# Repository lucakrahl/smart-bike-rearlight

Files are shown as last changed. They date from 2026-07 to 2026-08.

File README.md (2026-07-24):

# Smart Bike Rear Light

Prototyp eines intelligenten IoT-Fahrrad-Rücklichts (Bachelorarbeit, Maschinenbau
& Produktentwicklung B.Eng.). ESP32-Firmware mit IMU-gesteuertem Schluss-/Brems-
licht, 433-MHz-Funk-Blinkern und BLE-Telemetrie an eine Web-App.

## Struktur (Monorepo)
| Ordner | Inhalt |
|---|---|
| `firmware/` | PlatformIO-Projekt (ESP32, Arduino-Framework) |
| `webapp/` | PWA / Web-Bluetooth-App (später) |
| `docs/` | **Project Bible** (SSOT) + Wissensdatenbank |
| `hardware/` | Schaltplan, BOM |
| `cad/` | Gehäuse (später) |
| `testdata/` | Sensordaten für Host-Logik-Tests |

## Quickstart
```bash
# Abhängigkeiten holen & Firmware bauen
cd firmware
pio run -e esp32dev

# Flashen & Serial-Monitor
pio run -e esp32dev -t upload
pio device monitor -b 115200

# Host-Unit-Tests der Logik (ohne ESP32)
pio test -e native
```

## Arbeiten mit Claude Code
`CLAUDE.md` im Repo-Root ist der Projektkontext (wird automatisch geladen).
**Zuerst `docs/project_bible.md` lesen** — das ist die Single Source of Truth.
Implementiert wird gegen die SRS (Bible Kap. 2); jede Umsetzung referenziert die
Anforderungs-ID(s). Reihenfolge der Module: `docs/roadmap.md`.

## Voraussetzungen
VS Code · PlatformIO IDE · Claude Code · Git. ESP32 NodeMCU DevKit C V2
(CP2102-Treiber). Board `esp32dev`, Partition `huge_app` (No-OTA), 115200 Baud.

## Wichtiger Hinweis
Das Notbrems-Blinken (FR-TL-07) ist **standardmäßig deaktiviert** — ein blinkendes
rotes Rücklicht ist nach § 67 Abs. 4 StVZO unzulässig (nur Experimental-/Messzweck).

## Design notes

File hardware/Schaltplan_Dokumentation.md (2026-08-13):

# Begleitdokumentation zum Schaltplan

**Elektrischer Schaltplan – Intelligentes IoT-Fahrrad-Rücklichtsystem**
**Bachelorarbeit · Hochschule Düsseldorf · Luca Krahl**
**Zeichnungsstand:** Rev. 1.3 vom 10.08.2026 · Blatt 1 von 1 · A4 Querformat
**Änderung gegenüber Rev. 1.2:** Die Gate-Pull-Down-Widerstände **R2, R4 und R6 (je 10 kΩ) sind entfallen** — sie sind nicht bestückt. Das Gate jedes MOSFET liegt ausschließlich über den Serienwiderstand R1/R3/R5 am GPIO, die Source direkt an der Masse-Sammelschiene. Neuer Befund B-9. Bauteilzahl 27 → 24.
**Änderung gegenüber Rev. 1.1:** (a) Die Drahtantenne ANT2 am SRX882S ist entfallen — sie ist nicht verbaut; der Pin ANT trägt jetzt eine Nichtanschluss-Markierung. (b) Vollständige Neuanordnung des Blattes: die Blockrahmen A und C überschnitten sich, und in Block D lagen die Versorgungssymbole auf dem Rahmen. (c) In Block D ersetzen zwei durchgehende Sammelschienen (+5 V und GND) die neun einzelnen Versorgungssymbole.
**Änderung gegenüber Rev. 1.0:** Position von SW1 korrigiert — der Schalter sitzt im Akkupfad zwischen U1 OUT+ und U2 VIN+.
**Quellen:** Project Bible Kap. 4/5 · `firmware/include/pins.h` und `config.h` (Commit `1178017`) · Datenblätter im Projekt · Verdrahtungsklärung vom 09.08.2026

---

## A. Komponentenübersicht

| Ref. | Bauteil | Funktion | Versorgung | Schnittstelle |
|---|---|---|---|---|
| BT1 | LiPo LP103454, 3,7 V, 2000 mAh | Energiespeicher | — | B+/B− an U1 |
| J1 | USB-C-Buchse (Bestandteil von U1) | Ladeanschluss, von außen zugänglich | 5 V extern | — |
| U1 | TP4056 Typ-C mit DW01 | Laderegler 1 A, Tiefentlade- und Kurzschlussschutz | USB-C 5 V | B+/B−, OUT+/OUT− |
| U2 | MT3608 | Aufwärtswandler 3,7 V → 5,00 V (Trimmer) | von U1 OUT+ | VIN/VOUT |
| SW1 | Rastender Drucktaster IP65, 8 mm | Ein/Aus **im Akkupfad zwischen U1 OUT+ und U2 VIN+** | — | — |
| C1 | Elektrolytkondensator 1000 µF | Pufferung Reglereingang | +5 V ↔ GND | — |
| C2 | Elektrolytkondensator 1000 µF | Pufferung Reglerausgang | +3V3 ↔ GND | — |
| U3 | ESP32-DevKitC-32E (WROOM-32E), AMS1117-3.3 onboard | Hauptrechner | VIN 5 V → 3V3 | GPIO, I²C, UART2, PWM, BLE |
| IC2 | GY-521 / MPU-6050 | IMU, Bremserkennung | +3V3 | I²C 0x68 |
| IC3 | BMP280 | Barometer, Höhe | +3V3 | I²C 0x76 |
| IC4 | Quectel L86-M33 | GNSS GPS+GLONASS, interne Patch-Antenne | +3V3 (VCC und V_BCKP) | UART, 9600 Bd |
| U4 | SRX882S V2.0 | 433-MHz-Empfänger, superheterodyn | +3V3 (VCC und CS) | Digitalausgang DATA |
| Q1–Q3 | IRLZ44N (3×) | Low-Side-PWM-Treiber | — | Gate an GPIO |
| R1/R3/R5 | 100 Ω (3×) | Gate-Serienwiderstand | — | — |
| RN1–RN3 | je 8 × 100 Ω parallel = 12,5 Ω | Strombegrenzung je LED-Kanal | in Reihe zur LED | — |
| D1 | LED rot, 3-W-COB | Schluss- und Bremslicht | Anode an +5 V | PWM über Q2 |
| D2 | LED gelb, 3-W-COB | Blinker links | Anode an +5 V | PWM über Q1 |
| D3 | LED gelb, 3-W-COB | Blinker rechts | Anode an +5 V | PWM über Q3 |
| — | QIACHIP-Handsender, 2 Tasten | Blinkerauslösung, Codes 10967538 / 10967537 | eigene Batterie | 433 MHz ASK, drahtlos |

**Nicht verbaut, aber bisher in der Stückliste geführt:** die GNSS-Antenne „Namvo". Der L86 nutzt seine interne Patch-Antenne (18,4 × 18,4 × 4 mm); der Pin EX_ANT ist unbeschaltet.

**Ebenfalls nicht verbaut:** eine Drahtantenne am SRX882S. Bis Rev. 1.1 war am Pin ANT eine λ/4-Drahtantenne von 17,3 cm eingezeichnet. Die Längenangabe war für 433,92 MHz rechnerisch korrekt (λ = c/f = 69,1 cm, λ/4 = 17,3 cm), entsprach aber nicht dem gebauten Aufbau: Es ist kein Draht angeschlossen. Der Pin ANT ist ab Rev. 1.2 als Nichtanschluss gezeichnet. Zur beobachteten Wirkung s. Befund B-7.

Der Micro-USB-Anschluss des DevKitC dient ausschließlich der Programmierung und ist im montierten Zustand nicht zugänglich. Seine Masse liegt hardwareseitig auf derselben GND-Schiene; beim Flashen wird der Akkupfad getrennt.

---

## B. Pinbelegung

| ESP32-Pin | Funktion | Angeschlossene Komponente | Netzname |
|---|---|---|---|
| GPIO21 | I²C SDA | IC2, IC3 | `I2C_SDA` |
| GPIO22 | I²C SCL | IC2, IC3 | `I2C_SCL` |
| GPIO16 | UART2 RX | IC4 TXD1 (Pin 2) | `GNSS_TXD1` |
| GPIO17 | UART2 TX | IC4 RXD1 (Pin 1) | `GNSS_RXD1` |
| GPIO4 | Digitaleingang RF | U4 DATA | `RF_DATA` |
| GPIO25 | PWM Blinker links | R1 → Q1 Gate | `PWM_BLINK_L` |
| GPIO26 | PWM Schluss-/Bremslicht | R3 → Q2 Gate | `PWM_BRAKE` |
| GPIO27 | PWM Blinker rechts | R5 → Q3 Gate | `PWM_BLINK_R` |
| VIN | Versorgung 5 V | +5-V-Schiene (U2 VOUT+) | `+5V` |
| 3V3 | Versorgungsausgang AMS1117 | IC2, IC3, IC4, U4, C2 | `+3V3` |
| GND | Bezugspotential | gemeinsame Masse | `GND` |

Der Interrupt-Pin des MPU-6050 bleibt unbeschaltet, weil GPIO4 durch den RF-Empfänger belegt ist; die IMU wird gepollt.

---

## C. Versorgungskonzept

Der Strompfad verläuft in einer Kette: Die USB-C-Buchse speist den TP4056, dieser lädt den LiPo-Akku über B+/B− mit maximal 1 A. Die Last hängt bewusst an **OUT+** und nicht an B+, damit der im Modul enthaltene DW01 seinen Tiefentlade- und Kurzschlussschutz auch für die Systemlast ausübt. Von OUT+ führt der Akkupfad über den rastenden Schalter **SW1** auf den Eingang des Aufwärtswandlers MT3608, dessen Trimmer auf 5,00 V eingestellt ist. Dessen Ausgang bildet die **+5-V-Schiene**, an der zwei Verbraucher hängen: der ESP32 über seinen VIN-Pin und die drei LED-Zweige über ihre Vorwiderstandsnetze. Der auf dem DevKitC verbaute AMS1117-3.3 erzeugt daraus die **+3,3-V-Schiene**, an der ausschließlich die vier Peripheriemodule liegen. Gepuffert wird an beiden Seiten des Reglers mit je 1000 µF (C1 am Eingang, C2 am Ausgang).

SW1 trennt den Eingang des Wandlers. Im ausgeschalteten Zustand ist damit die gesamte 5-V-Schiene einschließlich der LED-Zweige stromlos, und zusätzlich entfällt der Ruhestrom des MT3608. Der Ladepfad USB-C → U1 → BT1 bleibt davon unberührt; das Gerät lädt also auch ausgeschaltet.

### Strombilanz

| Betriebsfall | Entnahme an +5 V | Leistung | Strom aus BT1 (η = 0,90) |
|---|---|---|---|
| Schlusslicht (D1 bei 20 % Duty) + ESP32 + Sensorik | 159 mA | 0,80 W | 0,24 A |
| Bremslicht 100 % + ESP32 + Sensorik | 338 mA | 1,69 W | 0,51 A |
| Bremslicht + beide Blinker 100 % | 786 mA | 3,93 W | **1,18 A** |

Zugrunde gelegt: I_LED = (5 V − 2,2 V) / 12,5 Ω = 224 mA je Kanal; ESP32 mit Sensorik 113 mA an 5 V. Der Strom aus BT1 fließt vollständig über SW1, da der Schalter im Akkupfad sitzt. Rechnerische Laufzeit im Dauerbetrieb mit Schlusslicht: rund **8 h**. Die Werte sind berechnet, nicht gemessen.

---

## D. Kommunikationsschnittstellen

**I²C** verbindet den ESP32 über GPIO21 (SDA) und GPIO22 (SCL) mit IC2 (0x68) und IC3 (0x76) auf einem gemeinsamen Bus. Pull-Up-Widerstände existieren ausschließlich modulintern gegen +3,3 V; externe Widerstände sind nicht verbaut.

**UART2** verbindet den ESP32 mit dem GNSS-Modul: GPIO17 als Sendeleitung auf RXD1, GPIO16 als Empfangsleitung von TXD1, 9600 Bd, 8N1, 1 Hz Ausgaberate.

**GPIO** wird für den 433-MHz-Empfänger genutzt: U4 gibt die demodulierten Daten als Digitalsignal auf GPIO4 aus. Der Chip-Select-Pin von U4 liegt fest auf +3,3 V, der Empfänger ist damit dauerhaft aktiv.

**PWM** steuert alle drei Leuchtenkanäle über die LEDC-Peripherie mit 5 kHz und 8 bit Auflösung.

**BLE 4.2** überträgt die Telemetrie unidirektional vom Gerät zur iOS-App. Es ist eine reine Funkstrecke ohne Leitungsbezug und im Schaltplan als Annotation am ESP32 vermerkt.

**433 MHz** bildet die Strecke vom QIACHIP-Handsender zu U4. Der Sender ist ein gekauftes Gerät mit eigener Batterie und nicht Bestandteil der Leiterplatte.

---

## E. Elektrische Plausibilitätsprüfung

Die Prüfung wurde am fertigen Schaltplan durchgeführt. Die Verbindungsprüfung erfolgte maschinell über die aus der Zeichnung exportierte Netzliste; die Bewertungen darunter sind analytisch. **An der Schaltung wurde nichts geändert.**

### E.1 Verbindungsprüfung (maschinell, bestanden)

Die exportierte Netzliste enthält 32 Netze. Alle 24 Bauteile sind vollständig verdrahtet; jedes Netz trägt mindestens zwei Knoten. Die einzigen Einzelknoten sind die sechs bewusst offenen Pins des L86 (1PPS, FORCE_ON, AADET_N, RESET, EX_ANT, NC) sowie der Pin ANT des SRX882S — alle im Schaltplan mit Nichtanschluss-Markierungen versehen. Stichproben: `GND` verbindet 16 Knoten, `+3V3` acht, `+5V` sechs, `I2C_SDA` und `I2C_SCL` je drei. Die Schalterposition ist maschinell bestätigt: SW1 liegt zwischen `Net-(U1-OUT+)` und `Net-(U2-VIN+)`.

### E.2 Befunde

**B-1 · UART-Pegel überschreitet die spezifizierte Eingangsgrenze des L86 [relevant].**
Das Datenblatt des L86 (Tab. 3) gibt für die Digitaleingänge RXD1, RESET und FORCE_ON **VIHmax = 3,1 V** an. Der ESP32 treibt GPIO17 mit 3,3 V. Der Wert liegt damit **0,2 V über der spezifizierten Obergrenze**, aber deutlich unter dem absoluten Grenzwert von 3,6 V (Tab. 11) — eine Zerstörung ist nicht zu erwarten, der Betrieb erfolgt jedoch außerhalb der zugesicherten Bedingungen. In Gegenrichtung ist die Lage unkritisch: TXD1 liefert nominal 2,8 V gegen eine Eingangsschwelle des ESP32 von 0,75 · 3,3 V = 2,48 V, also 0,32 V Reserve. *Lösungsvorschlag:* Spannungsteiler 1 kΩ / 10 kΩ oder ein 1-kΩ-Serienwiderstand in der Leitung GPIO17 → RXD1. *Freigabe erforderlich, ich ändere nichts eigenmächtig.*

**B-2 · Verlustleistung des Boardreglers unter Spitzenlast [prüfen].**
Am AMS1117-3.3 des DevKitC hängen jetzt alle vier Peripheriemodule. Im ungünstigsten Fall summieren sich ESP32-Sendespitze (~250 mA), L86-Spitzenstrom (100 mA laut Datenblatt Tab. 12) und die beiden I²C-Sensoren (4 mA) auf rund 354 mA. Bei 1,7 V Spannungsabfall sind das **0,60 W** im SOT-223-Gehäuse; bei einem Wärmewiderstand von 60–100 K/W entspricht das 36–60 K Übertemperatur. Der Strom liegt innerhalb der Belastbarkeit des Reglers, die Verlustleistung ist aber nicht vernachlässigbar — und es ist derselbe Pfad, in dem der BLE-Brownout des Altboards saß. *Empfehlung:* im Rahmen der ohnehin offenen Messung NFR-PWR-02 mitmessen.

**B-3 · Laden unter Last [prüfen].**
Da die Last an OUT+ hängt, speist der TP4056 im Ladebetrieb gleichzeitig Akku und System. Der Laststrom fließt durch die Strommessung des Ladereglers; die Abschalterkennung kann dadurch verzögert oder verhindert werden. Das ist eine bekannte Eigenschaft dieser Topologie und kein Verdrahtungsfehler, gehört aber dokumentiert.

**B-4 · Fehlende hochfrequente Entkopplung [dokumentieren].**
Das L86-Datenblatt (Kap. 3.3) empfiehlt 10 µF und 100 nF unmittelbar am VCC-Pin. Verbaut sind ausschließlich die beiden 1000-µF-Elkos an den Schienen. Elektrolytkondensatoren haben oberhalb einiger 10 kHz keine wirksame Impedanz mehr; für die Störfestigkeit des GNSS-Empfängers ist das eine Abweichung von der Herstellerempfehlung.

**B-5 · Kein Verpolungs- und kein Überstromschutz [bestätigt, dokumentieren].**
Eine Sicherung existiert nicht. Ein Kurzschluss im LED-Zweig würde nur durch die Strombegrenzung des MT3608 und den DW01 des TP4056 begrenzt. Ein Verpolungsschutz an der Akkuklemme fehlt ebenfalls. Beides ist bewusster Aufbaustand und in Kap. 12 der Project Bible bereits als Risiko geführt.

**B-6 · Schalterstrom durch die Position im Akkupfad [prüfen].**
Da SW1 vor dem Aufwärtswandler sitzt, führt er dessen Eingangsstrom. Im Worst Case sind das **1,18 A** bei 3,7–4,2 V; auf der 5-V-Seite wären es bei gleicher Leistung nur 0,79 A gewesen. Für den verbauten 8-mm-Drucktaster liegt kein Datenblatt vor, Nennstrom und Kontaktwiderstand sind damit unbelegt. Ein erhöhter Kontaktwiderstand wirkt an dieser Stelle zusätzlich direkt auf den Eingangsspannungsbereich des MT3608, weil er den ohnehin niedrigen Akkuspannungspegel weiter absenkt. *Empfehlung:* Datenblatt beschaffen oder den Spannungsabfall über dem geschlossenen Kontakt unter Last messen — sinnvollerweise zusammen mit NFR-PWR-02.

### E.3 Als unkritisch geprüft

**GPIO-Belegung.** Die acht verwendeten Pins sind paarweise verschieden. GPIO4 ist kein Strapping-Pin. Die Strapping-Pins GPIO0, 2, 5, 12 und 15 sind unbeschaltet. GPIO16 und GPIO17 sind beim WROOM-32E frei nutzbar — die Einschränkung gilt nur für WROVER-Module mit PSRAM. GPIO25 bis 27 sind als Digitalausgänge ohne Boot-Bedingungen verwendbar.

**I²C-Bus.** Adressen 0x68 und 0x76 kollidieren nicht. Zwei modulinterne Pull-Ups von typisch je 4,7 kΩ ergeben parallel etwa 2,35 kΩ; daraus folgt ein Low-Strom von 1,4 mA, deutlich unter der Senkfähigkeit des ESP32 von 3 mA nach I²C-Spezifikation. Die Anstiegszeit beträgt bei geschätzten 50 pF Busskapazität rund 0,1 µs gegen ein zulässiges Maximum von 1 µs im Standard-Modus. Beide Sensoren liegen an derselben 3,3-V-Schiene wie der Controller, ein Pegelwandler ist nicht erforderlich.

**UART-Kreuzung.** TX und RX sind korrekt gekreuzt (GPIO17 → RXD1, TXD1 → GPIO16).

**MOSFET-Ansteuerung.** Der IRLZ44N ist ein Logic-Level-Typ mit einer Gate-Schwellspannung von 1,0 bis 2,0 V. Bei 3,3 V Ansteuerung und 224 mA Laststrom liegt der Durchlasswiderstand bei etwa 0,05 Ω, die Verlustleistung damit bei 2,5 mW je Transistor — thermisch belanglos. Die Gate-Zeitkonstante beträgt mit 100 Ω und einer Eingangskapazität von rund 3,3 nF etwa 0,33 µs; bei 5 kHz Schaltfrequenz (200 µs Periode) entfallen damit unter 1 % der Periode auf die Umschaltvorgänge. Ein Gate-Pull-Down ist **nicht bestückt**; zur Folge für den Reset- und Bootzustand s. Befund B-9. Der Transistor ist mit 47 A Nennstrom für 224 mA erheblich überdimensioniert; das ist kein Fehler, sondern eine Folge der Bauteilverfügbarkeit und darf so begründet werden.

**LED-Zweige.** Jeder Kanal besitzt eine Strombegrenzung. Die Verlustleistung im Widerstandsnetz beträgt 0,63 W, verteilt auf acht Widerstände also 78 mW je Bauteil — bei 0,25-W-Typen eine Auslastung von 31 %.

**Thermische Stabilität der Vorwiderstandslösung.** Der in Kap. 12 der Project Bible geführte Verdacht auf thermisches Weglaufen lässt sich entkräften. Mit I = (5 V − V_f)/12,5 Ω und einem Temperaturkoeffizienten der Flussspannung von etwa −2 mV/K ergibt sich dI/dT = 0,16 mA/K. Über eine Erwärmung von 50 K steigt der Strom damit um 8 mA, also um 3,6 %. Entscheidend ist, dass über dem Widerstand mit 2,8 V mehr Spannung abfällt als über der LED mit 2,2 V — die Schaltung ist dadurch hinreichend steif. Ein thermisches Weglaufen ist bei dieser Dimensionierung **nicht zu erwarten**. Das Risiko kann in der Bible entsprechend herabgestuft werden.

---

**B-7 · SRX882S ohne Antenne betrieben [beobachtet, nicht gemessen].**
Der Empfänger arbeitet ohne angeschlossene Antenne; der Empfang erfolgt über die Anschlussfahne und die Leiterbahnen des Moduls. Der Verfasser berichtet, dass die Funkverbindung ohne den zuvor angeschlossenen 17,3-cm-Draht **zuverlässiger** arbeitet als mit ihm.

Das ist plausibel, aber nicht gemessen. Eine λ/4-Monopolantenne setzt eine leitende Gegenfläche (Counterpoise) von mindestens λ/4 Ausdehnung voraus; auf einem Lochrasteraufbau ohne durchgehende Massefläche fehlt diese. Der Draht wirkt dann weniger als abgestimmter Strahler denn als breitbandige Sammelfläche und koppelt bevorzugt die Störspektren des MT3608-Schaltreglers und der 5-kHz-PWM-Stufe ein, die beide unmittelbar daneben liegen. Der Superheterodyn-Empfänger verliert dadurch Rauschabstand, obwohl seine Empfindlichkeit steigt. Ohne Draht sinken Empfindlichkeit **und** Störpegel; bei den hier auftretenden Entfernungen von wenigen Metern überwiegt offenbar der Gewinn an Rauschabstand.

**Einordnung.** Die Aussage, ohne Antenne sei der Empfang besser, ist eine Beobachtung des Verfassers und keine Messung. Belastbar wäre sie erst über eine Reichweitenmessung mit und ohne Draht bei gleicher Sendeleistung und gleicher Ausrichtung. Diese Messung ist nach dem Umfangsschnitt vom 10.08.2026 nicht Teil der Arbeit. Für die Zeichnung gilt der gebaute Zustand: kein Draht, Nichtanschluss am Pin ANT. In den Ausblick gehört der Hinweis, dass eine durchgehende Massefläche unter dem Empfängermodul die Voraussetzung dafür wäre, eine abgestimmte Antenne überhaupt sinnvoll zu betreiben.

**B-9 · Kein Gate-Pull-Down bestückt [dokumentierte Abweichung].**
Die ursprünglich vorgesehenen Widerstände R2, R4 und R6 (je 10 kΩ, Gate gegen Masse) sind im Aufbau nicht vorhanden. Das Gate jedes IRLZ44N ist ausschließlich über den Serienwiderstand von 100 Ω mit dem zugehörigen GPIO verbunden, die Source liegt direkt an Masse.

**Wirkung im Normalbetrieb: keine.** Sobald die Firmware den Pin über `ledcAttach()` als PWM-Ausgang konfiguriert hat, treibt der GPIO das Gate niederohmig; der Pull-Down wäre in diesem Zustand ohnehin nur eine parallele Last von 10 kΩ und ohne Einfluss. Die Gate-Zeitkonstante von 0,33 µs bleibt unverändert.

**Wirkung außerhalb des Normalbetriebs.** Zwischen dem Aufheben des Reset und der Pin-Konfiguration in `setup()` ist der GPIO hochohmig. Ohne Pull-Down ist das Gate in diesem Fenster **potentialfrei**. Bei einer Eingangskapazität von rund 3,3 nF und einer Gate-Schwellspannung des IRLZ44N von 1,0 bis 2,0 V genügt eine geringe eingekoppelte Ladung, um den Transistor teilweise leitend werden zu lassen. Die Dauer des Fensters umfasst Bootloader und Arduino-Initialisierung und liegt in der Größenordnung einiger hundert Millisekunden; sie wurde **nicht gemessen**.

**Bewertung der Folgen.** Für den roten Kanal ist die mögliche Fehlwirkung ein kurzzeitiges Aufleuchten des Schluss-/Bremslichts — für eine Rückleuchte die sichere Richtung, weil sie die Sichtbarkeit erhöht statt sie zu verringern. Für die beiden gelben Kanäle wäre es ein kurzzeitiges Fehlsignal in eine Abbiegerichtung; da es ausschließlich unmittelbar nach dem Einschalten auftreten kann, also im Stand, ist die praktische Gefährdung gering. Beim Flashen und bei den Boot-Kontrollen ist ein solches Aufleuchten **nicht beobachtet** worden.

**Warum keine Nachbesserung erfolgt.** Ein interner Pull-Down des ESP32 (typisch 45 kΩ) ließe sich in `setup()` aktivieren, wäre aber erst nach der Pin-Konfiguration wirksam und würde das Fenster deshalb nur verkürzen, nicht schließen. Vollständig schließen lässt es sich nur durch einen physischen Widerstand am Gate. Die Firmware ist seit dem 10.08.2026 eingefroren (Project Bible Kap. 12.2), und der Aufbau wird nicht mehr geändert. Der Punkt wird deshalb als **dokumentierte Abweichung** geführt und gehört als konkrete Empfehlung in den Ausblick: In einer Leiterplattenausführung ist ein Gate-Pull-Down von 10 bis 100 kΩ je Kanal vorzusehen.

## F. Offene Punkte

| Nr. | Punkt | Status |
|---|---|---|
| F-1 | Pegelanpassung GPIO17 → L86 RXD1 (Befund B-1) | Entscheidung des Verfassers erforderlich |
| F-2 | Messung der Verlustleistung am AMS1117 unter Spitzenlast (B-2) | offen, mit NFR-PWR-02 zu verbinden |
| F-3 | Verhalten des TP4056 beim Laden unter Last (B-3) | offen, messtechnisch zu prüfen |
| F-4 | Fehlende 10 µF / 100 nF am L86-VCC (B-4) | dokumentierte Abweichung |
| F-5 | Datenblatt der 3-W-COB-LED (Hersteller Vrabocry) | fehlt weiterhin; V_f = 2,2 V ist Mittelwert der Produktangabe 2,0–2,4 V |
| F-6 | Photometrischer Nachweis der Lichtstärke nach § 67 StVZO | offen, separate Messung |
| F-7 | Wirkungsgrad des MT3608 unter realer Last | angenommen η = 0,90, nicht gemessen |
| F-8 | Namvo-GNSS-Antenne in der Stückliste als nicht verbaut kennzeichnen | Dokumentationskorrektur |
| F-9 | Anordnung der Patch-Antenne im Gehäuse | Datenblatt fordert freie Sicht nach oben, nichtmetallisches Gehäuse, ≥ 10 mm Abstand zur BLE-Antenne des ESP32 |
| F-10 | Nennstrom und Kontaktwiderstand von SW1 (B-6) | Datenblatt fehlt; Messung des Spannungsabfalls unter Last empfohlen |
| F-11 | Reichweite der 433-MHz-Strecke ohne Antenne (B-7) | Beobachtung des Verfassers, nicht gemessen; Vergleichsmessung mit und ohne Draht wäre der Beleg |
| F-12 | Stückliste: Drahtantenne 17,3 cm am SRX882S als nicht verbaut kennzeichnen | Dokumentationskorrektur analog F-8 |
| F-13 | Stückliste: Positionen 10-kΩ-Pull-Down (3×) **streichen** statt ergänzen (B-9) | Sie sind nicht bestückt; der bisherige offene Punkt forderte fälschlich ihre Aufnahme |
| F-14 | Dauer des potentialfreien Gate-Fensters nach Reset messen (B-9) | Nicht gemessen; für die Bewertung der Fehlwirkung wäre der Wert die fehlende Größe |

Alle Größen im Schaltplan stammen aus belegten Projektquellen. Erfunden wurde nichts; die einzige rechnerische Annahme ist die mittlere Flussspannung von 2,2 V, die als solche gekennzeichnet ist.

---

## G. Dateien

| Datei | Inhalt |
|---|---|
| `schaltplan_fahrrad_ruecklichtsystem.kicad_sch` | KiCad-7-Schaltplan, in KiCad direkt zu öffnen und zu bearbeiten; die Symbolbibliothek ist in der Datei eingebettet, es werden keine externen Bibliotheken benötigt |
| `schaltplan_fahrrad_ruecklichtsystem.pdf` | Vektor-PDF, A4 Querformat, schwarzweiß — für die Bachelorarbeit |
| `schaltplan_fahrrad_ruecklichtsystem_farbe.pdf` | dieselbe Zeichnung im KiCad-Farbschema |
| `schaltplan_fahrrad_ruecklichtsystem.svg` | Vektorgrafik zur Weiterverarbeitung |
| `netzliste.net` | aus der Zeichnung exportierte Netzliste (Grundlage der Verbindungsprüfung E.1) |
| `Schaltplan_Dokumentation.md` | dieses Dokument |
| `gen.py`, `symlib.py` | Erzeugungsskripte, mit denen die Zeichnung reproduzierbar ist |

Die Zeichnung enthält keine Informationen, die ausschließlich über Farbe transportiert werden; die schwarzweiße Fassung ist vollständig gleichwertig.

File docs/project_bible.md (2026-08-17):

# Project Bible — Smartes Fahrrad-Rücklicht
**Bachelorarbeit Krahl · Maschinenbau & Produktentwicklung (B.Eng.)**
**Version 0.25 · Stand 17.08.2026 · Status: aktiv gepflegt (Single Source of Truth)**

> Diese Project Bible ist die oberste Wissensinstanz des Projekts. Bei Widersprüchen zwischen Chat-Historie und Project Bible gilt ausschließlich die Project Bible. Chats dienen der Diskussion und Entscheidungsfindung; der offizielle Projektstand steht ausschließlich hier.

---

## 0. Meta & Änderungsprotokoll

### 0.1 Geltungsregeln
- Die Project Bible bildet jederzeit den offiziellen Entwicklungsstand des Gesamtsystems ab.
- Widerspricht eine frühere Chat-Aussage der Project Bible, gilt die Project Bible.
- Kapitel 10 (Entwicklungsentscheidungen) wird als lebendes Änderungsprotokoll geführt.
- Trennung der Ebenen: **Project Bible** = offizieller Stand · **Kapitel 10** = Begründung der Entscheidungen · **Chats** = Diskussion.

### 0.2 Kennzeichnungslegende
- **[gesichert]** — durch mehrere Quellen bestätigt oder vom Nutzer freigegeben.
- **[Annahme]** — plausibel, aber messtechnisch/dokumentarisch noch nicht verifiziert.
- **[offen]** — in Klärung, noch nicht entschieden.
- **[geplant]** — beschlossen und spezifiziert, aber noch nicht umgesetzt oder noch nicht verifiziert.

### 0.3 Änderungsprotokoll
| Version | Datum | Änderung | Anlass |
|---|---|---|---|
| 0.1 | 21.07.2026 | Erstkonsolidierung als Analysedokument. | Projektaufnahme |
| 0.2 | 21.07.2026 | 12-Kapitel-Zielstruktur. SRS-Block A. | Freigabe Block A |
| 0.3 | 21.07.2026 | SRS-Block B (Zustandsmodell). | Freigabe Block B |
| 0.4 | 21.07.2026 | SRS-Block C (Detaillogik); Norm-Grundlage § 67/ECE. | Freigabe Block C |
| 0.5 | 21.07.2026 | SRS-Block D + E (Fehler & Sicherheit). | Freigabe Block D+E |
| 0.6 | 21.07.2026 | SRS-Block F (nichtfunktional); Akku LP103454. | Freigabe Block F |
| 0.7 | 21.07.2026 | SRS-Block G + H. **SRS (Phase 1) vollständig.** | Freigabe Block G+H |
| 0.8 | 21.07.2026 | Phase 3: Monorepo + PlatformIO angelegt, Umgebung lauffähig (pioarduino, Core 3.3.11). | Setup abgeschlossen |
| 0.9 | 21.07.2026 | M1 (Rücklicht-Region R2) in Umsetzung: FSM + Host-Tests. Detailklarstellungen FR-TL-03, FR-TL-06, FR-TL-07. | Implementierung M1 |
| 0.10 | 26.07.2026 | Implementierungsstand M1–M4 hardwarevalidiert, M5 Teil A (BMP280) validiert; zentrale I²C-Bus-Initialisierung; BMP280 FORCED-Mode. | Impl. M1–M5A |
| 0.11 | 29.07.2026 | App-Plattform: native iOS-App (Core Bluetooth) statt Web-App/PWA. | Plattform-Entscheidung App |
| 0.12 | 30.07.2026 | BLE-Brownout-Fallstudie; Board-Wechsel auf Espressif ESP32-DevKitC-32E beschlossen. | Root-Cause-Analyse BLE-Brownout |
| 0.13 | 01.08.2026 | Board-Tausch ausgeführt und validiert; iOS-App-Stand nachgezogen. | BLE-Validierung + App-Stand |
| 0.14 | 05.08.2026 | Telemetrie-Frame um `brake_light_pct` erweitert, 80→81 Byte, Schema-Version 1→2. | Frame-Erweiterung |
| 0.15 | 05.08.2026 | Serial-Bench-Validierung der Bremslicht-Logik; iOS-App am realen iPhone verifiziert. | Bench-Validierung |
| 0.16 | 06.08.2026 | **Feldtest 06.08.2026:** IMU-Bremserkennung im Realbetrieb falsifiziert (r = −0,132, n = 939). Ursache analytisch belegt. Neues Kap. 9.4. Architekturentscheidung V-B. | Feldtest-Auswertung |
| **0.17** | **09.08.2026** | **Große Revision. (a) Stufe 1 (`motion_filter`, Normbetrags-Gate) implementiert, host-getestet und am 08.08.2026 im Feld verifiziert — die Bremserkennung funktioniert; neues Kap. 9.5. Der Validierungsstatus von `motion_filter` wird von „im Feld falsifiziert" auf „im Feld verifiziert" heraufgestuft. (b) Zwei neue Firmware-Befunde: die Mindesthaltezeit nach FR-TL-06 ist im Fahrbetrieb unwirksam (Mangel), und `brake_decel_ms2` trägt eine geschwindigkeitsabhängige Grundlinie (quantifizierte Grenze). (c) Zeitverhalten erstmals im Fahrbetrieb gemessen: 6,7 ms Worst Case statt 0,651 ms am Prüfstand. (d) Methodische Korrektur: die Zahl r = −0,132 aus v0.16 wurde ohne Berücksichtigung der Latenz der GNSS-Referenzkette gerechnet und ist als Gütemaß nicht belastbar. (e) Elektronik vollständig geklärt und dokumentiert: Schaltplan Rev. 1.0 erstellt (Kap. 5.4), sechs offene Verdrahtungspunkte geschlossen, Energiebilanz methodisch korrigiert (13 h → ~8 h), GNSS-Antenne als nicht verbaut erkannt. (f) Einbaulage der IMU um 180° gedreht; Achsentransformation spezifiziert, noch nicht implementiert.** | Messfahrt, Schaltplan, Verdrahtungsklärung |
| **0.18** | **09.08.2026** | **Korrektur der Schalterposition.** SW1 sitzt im **Akkupfad zwischen U1 OUT+ und U2 VIN+** und trennt damit den Eingang des Aufwärtswandlers — nicht, wie in v0.17 und im Schaltplan zunächst dargestellt, zwischen MT3608-Ausgang und 5-V-Schiene. Funktional bleibt die Wirkung gleich (die gesamte 5-V-Schiene ist stromlos), elektrisch ändert sich der Schalterstrom: er fließt nun auf der Akkuseite und beträgt im Worst Case 1,18 A statt 0,79 A. Neuer Befund B-6. Schaltplan Rev. 1.1, Kap. 4.1, 5.1, 5.2, 5.4, 11.2 und 12 angepasst. | Korrekturhinweis des Verfassers |
| **0.19** | **10.08.2026** | **Firmware-Abschluss (Commit `835c7b3`, geflasht).** (a) Einbaulage-Transformation implementiert und auf das Gerät gebracht: `imu_mount_orientation.h` an der Treibergrenze, `IMU_MOUNT_SIGN_X/Y/Z` = −1/−1/+1 auf Beschleunigung und Drehrate, eigener Host-Test. Kap. 4.3 wechselt von [geplant] auf [umgesetzt]. (b) **Mangel M-01 behoben:** der Haltewert der Mindesthaltezeit wird nur noch oberhalb der Einschaltschwelle nachgeführt; Regressionstest ergänzt, der das Hystereseband monoton durchläuft. (c) **Umfangsschnitt Firmware:** FR-CFG-02 (serielles Kalibrier-Interface) und FR-CFG-03 (NVS-Konfiguration) werden nicht umgesetzt und als begründete Abgrenzung geführt (neues Kap. 12.2); alle Kalibrierwerte sind Übersetzungszeit-Konstanten. (d) Auslieferungsstand: alle Debug-Ausgaben entfernt, `DEBUG_SERIAL = false`. Daraus folgt eine **Korrektur an Befund B7**: die Zuordnung der 6,7 ms Worst-Case-Schleifenzeit allein zum GNSS-Slot war nicht belegt, weil drei 1-Hz-Debug-Prints im selben Messfenster lagen (Kap. 9.5.5). (e) `lib_deps` versionsfest gepinnt (Reproduzierbarkeit, NFR-EXT-01); tote Symbole entfernt; alle `TODO(offen)`-Marker in begründete Abgrenzungen umformuliert. (f) Host-Tests **126/126** grün. **Die Firmware ist damit abgeschlossen und eingefroren.** | Firmware-Abschluss |
| **0.20** | **10.08.2026** | **Werkstoffkorrektur Gehäuse: PETG statt PLA.** Frühere Fassungen nannten in Kap. 4.1 und Kap. 8 durchgängig PLA; gefertigt wird im FDM-Verfahren aus PETG. Die Angabe war eine Fehlangabe, keine Änderung der Auslegung. Thermisch günstiger (höhere Glasübergangstemperatur, zäher, witterungsbeständiger). Ergänzt: Verbindungstechnik mit Einschmelzgewinden M3 × 5 × 5 sowie Schrauben M3 × 6 und M3 × 8; Hinweis, dass die Konstruktion bearbeitet und gedruckt ist und der Konstruktionsstand noch aufzunehmen ist. | Korrekturhinweis des Verfassers |
| **0.21** | **11.08.2026** | **Normkorrektur, konstruktive Anforderungen und Quellenprüfung.** (a) **ECE R6 ist für Fahrrad-Fahrtrichtungsanzeiger nicht einschlägig.** § 67 Abs. 5 StVZO nennt UN/ECE R50 bzw. UN R148 (Genehmigung), R74 (Anbau) und R60 (Bedienteile). Der Zahlenwert 1,5 Hz ist primär in UN-R53 § 6.3.8.1 belegt (90 ± 30/min) und wird als **Analogie** geführt, weil R53 für Krafträder gilt. Kap. 0.4, 2.7, 2.8 und das Glossar angepasst. (b) **§ 67 Abs. 5 StVZO lässt Fahrtrichtungsanzeiger am Fahrrad ausdrücklich zu** — die gegenteilige Aussage in `Parameterherleitung.md` ist zu korrigieren. (c) **Neuer Block 2.13: zehn konstruktive Anforderungen (KON-01 bis KON-10)**, abgeleitet aus dem eingefrorenen Elektronikstand, mit Unterscheidung in Forderung und Wunsch. (d) **Trockenbetrieb als ausdrückliche Systemgrenze**: es gibt keine Umgebungsanforderungen, ein Dichtheitsnachweis wurde nicht geführt. (e) Vier Befunde aus der Datenblattprüfung des IRLZ44N und aus [Hering u. a.]: C_iss ist 1700 pF und nicht 3,3 nF, R_DS(on) ist bei 3,3 V nicht spezifiziert, V_GS(th) ist bei 250 µA definiert und keine Vollansteuerungsgrenze, und der Temperaturkoeffizient der LED-Durchlassspannung beträgt **−1 mV/K** statt −2 mV/K. Kap. 5.4 und 12.1 angepasst. (f) Rollen der Funkstrecke geklärt und Kennwerte des SRX882S aufgenommen; die Empfindlichkeit beträgt −107 dBm und nicht −114 dBm. (g) Werkstoffbegründung PETG auf die thermische Belastung gestützt, Witterungsbeständigkeit als Nebeneffekt geführt. | Quellenprüfung, Kapitel 3 der Thesis |
| **0.22** | **12.08.2026** | **Rücknahme des GNSS-Integritätsbefunds und Kapitel 4 der Thesis.** (a) **Der Befund „73 km/h Scheingeschwindigkeit im Stand bei FIX_OK" ist zurückgezogen.** Fahrt 5 des Feldtests vom 06.08.2026 wurde nach Klarstellung des Verfassers aus dem *fahrenden* Auto durchgeführt. Die gemeldete Geschwindigkeit war damit real und kein Integritätsfehler. Die Abdeckung hat das Signal nicht ausreichend gedämpft, der Versuch ist ergebnislos und **kein Beleg**. Kap. 0.4, 9. (Validierungstabelle), 9.4, 10 und 12.1 angepasst. (b) Die Architekturentscheidung V-B bleibt unverändert bestehen. Sie trägt auf vier voneinander unabhängigen, weiterhin belegten Punkten: Höchstrate 10 Hz gegen 100 Hz, Latenz 200–400 ms gegen NFR-RT-01, rund 20 s bis zum Erstfix und ein 90-%-Quantil des Differentiationsrauschens bis 1,97 m/s² gegen eine Ansprechschwelle von 2,0 m/s². (c) **Kapitel 4 der Thesis (Systemkonzept) geschrieben**, mit Tabelle 4-1 (Variantenvergleich) und den Abbildungen 4-1 bis 4-4. Das Kriterium „wissenschaftlicher Gehalt für die Arbeit" aus der internen Variantenbewertung wird in der Thesis-Tabelle bewusst nicht geführt, weil es kein ingenieurtechnisches Kriterium ist. (d) Der ausgelieferte Firmwarestand entspricht funktional V-C mit vorbereiteter, aber abgeschalteter Stufe 2. Diese Formulierung wird in der Arbeit so verwendet. | Klarstellung des Verfassers, Thesis-Kapitel 4 |
| **0.23** | **13.08.2026** | **Hardwarestand gegen Fotos, Schaltplan Rev. 1.3 und zwei neue Datenblätter abgeglichen; Kapitel 5 der Thesis geschrieben.** (a) **Bestückungskorrekturen:** SW1 ist ein **Wippschalter** und kein Drucktaster IP65. Die **Gate-Ableitwiderstände R2/R4/R6 sind nicht bestückt** — Schaltplan Rev. 1.3 führt das als Befund B-9. **ANT2 ist nicht verbaut**, der Empfang erfolgt über die Anschlussflächen des Moduls; der Widerspruch zwischen Kap. 4.1 und 11.2 ist damit aufgelöst. (b) **Datenblatt der roten Leuchte beschafft** (NTE30180-R, typgleiches Vergleichsbauteil): Dauerstrom **800 mA** statt der bisher geführten 400–500 mA, Durchlassspannung 2,0–2,6 V bei 400 mA, Sperrschichttemperatur typisch 115 °C gegen Grenzwert 120 °C. Der Kanalstrom wird als Spanne **208 bis 240 mA** mit 224 mA als Rechenwert geführt. (c) **Wirkungsgrad des MT3608 bleibt eine Annahme.** Das Datenblatt nennt nur „bis zu 97 %" ohne Arbeitspunkt und ohne Kennlinie; η = 0,90 wird beibehalten, die Laufzeit zusätzlich als Spanne 7,9 bis 8,8 h angegeben. (d) **Latenzangabe korrigiert:** die 200–400 ms waren eine eigene Abschätzung und nicht aus dem Datenblatt belegbar. Maßgeblich ist der gemessene Versatz von 1,6 bis 2,0 s aus der Messfahrt. Ratengrenze des Empfängers und Grenze der seriellen Schnittstelle werden getrennt geführt. (e) **Funkstrecke erstmals gemessen:** 19 von 20 bzw. 18 von 20 erkannten Tastendrücken in Einbaulage mit Körper im Signalweg, ohne Drahtantenne. Der offene Punkt aus Kap. 11.2 ist damit geschlossen. (f) Schaltplanstand auf **Rev. 1.3 (10.08.2026)** gehoben. (g) Fotodokumentation des Aufbaus in die Datengrundlage aufgenommen. | Fotoabgleich, Datenblätter, Thesis-Kapitel 5 |
| **0.24** | **13.08.2026** | **Präzisierungen aus der Quellenarbeit zu Kapitel 5.1.** (a) Das **ersetzte Mikrocontrollerboard wird namentlich geführt**: AZ-Delivery ESP-32 Dev Kit C V2, belegt über die Herstelleranleitung AZ281 aus der Projektablage. Bisher stand dort nur „Board eines anderen Anbieters". (b) **Wichtige Präzisierung zum Board-Tausch:** Beide Boards tragen denselben Reglertyp AMS1117-3.3. Der Brownout ist deshalb **keine generische Eigenschaft** dieses Reglertyps oder der Plattform, sondern nach der Fallstudie eine Grenze oder ein Defekt des konkreten Altboards, wahrscheinlich durch umfangreiches Rework verursacht. Diese Einordnung ist im Thesis-Text zu übernehmen. (c) **L86 präzisiert:** Empfang von GPS und GLONASS auf L1; SBAS und QZSS sind unterstützt, am Einsatzort ist davon nur SBAS in Form von EGNOS wirksam, weil QZSS ein regionales System über Asien und Ozeanien ist. (d) Belegliste auf [17] bis [27] erweitert; die Alternativen der Komponentenauswahl sind jetzt einzeln belegt. | Quellenarbeit Kapitel 5.1 |
| **0.25** | **17.08.2026** | **Thesis-Kapitel 6 bis 10 abgeschlossen, Anhangsstruktur festgeschrieben, Projektarchiv veröffentlicht.** (a) **Anhangsstruktur der Thesis verbindlich festgelegt** (neues Kap. 12.3): A Schaltplan, Stückliste und Bestückungsplan · B Anforderungsliste mit Nachweisführung · C Projektarchiv, Rohdaten und Auswertungsskripte · D Herleitung der Zahlenwerte der Signalaufbereitung · E Schnittstellenbeschreibung des Telemetriepakets · F Dokumentation der Nutzung generativer KI-Werkzeuge. Die KI-Dokumentation steht ausdrücklich an letzter Stelle. (b) **Nachweisart je Anforderung festgelegt** — der seit Kap. 2.13 offene Punkt ist geschlossen. Vier Arten: Analyse, Inspektion, Test, Messung. Zusätzlich eine vierstufige Bewertungsskala. 73 der 79 Anforderungen sind erfüllt und nachgewiesen; eingeschränkt sind FR-TL-06, FR-TL-07, FR-CFG-02, FR-CFG-03, NFR-PWR-02 und KON-06. (c) **Lücke im Anforderungsbestand erkannt:** Für die Funkstrecke existiert keine Anforderung an die Erkennungsrate, obwohl sie die einzige Eingabeschnittstelle des Systems ist. (d) **Neuer Messbefund zum Zeitverhalten:** Die erhöhten Schleifenzeiten treten periodisch mit 1,00 s auf, insgesamt 175 Ereignisse über 177,86 s. (e) **Randbedingung von Prüfstandsversuch D festgeschrieben:** Dauerbremsung von 3,9 m/s² über vier Sekunden, alte und neue Aufbereitung parallel auf derselben Eingangsfolge. (f) **Formelzeichen vereinheitlicht:** Der Neigungswinkel der Fahrbahn trägt das Zeichen β, α bleibt dem Gewichtungsfaktor des Filters vorbehalten, δ wird neu geführt. (g) **Tabelle 6-1 aus dem Fließtext in Anhang D verlagert.** Der Wert 6,0 m/s² für das Rückfallkriterium war bisher nur im Quelltext geführt und wird in den Thesis-Text aufgenommen. (h) **Korrelationswerte in der Thesis wieder aufgenommen:** +0,85 und im Median +0,15 bei einheitlich herausgerechnetem Versatz von 2,0 s. (i) **Projektarchiv veröffentlicht** unter https://github.com/lucakrahl/smart-bike-rearlight, eingefrorener Stand a6e3a0c vom 17.08.2026. Als Folge: die beiden Transferdokumente zur Firmware werden entfernt, der Feldtestbericht erhält einen datierten Nachtrag mit drei zurückgezogenen Befunden, cad/README.md wird von PLA auf PETG korrigiert. | Thesis-Kapitel 6–10, Gesamtdurchsicht, Veröffentlichung des Archivs |

### 0.4 Datengrundlage
| Quelle | Zeitstempel | Aussagekraft |
|---|---|---|
| Projektübergabe-Dokument | „Stand Juni 2026" | Detaillierteste Einzelquelle der Frühphase |
| **Repo `smart-bike-rearlight`, Commit `835c7b3` (Firmware-Abschluss)** | **10.08.2026** | **Maßgeblicher und endgültiger Firmware-Stand** |
| Repo `smart-bike-rearlight`, Commit `1178017` | 07.08.2026 | Stand der Messfahrt-Aufzeichnung vom 08.08.2026 |
| `firmware/include/pins.h`, `config.h` | Commit `835c7b3` | Verbindliche Pin- und Parameterquelle |
| **Verdrahtungsklärung mit dem Verfasser** | **09.08.2026** | **Sechs bis dahin offene Elektronikpunkte geklärt (Kap. 5)** |
| **Schaltplan Rev. 1.0 (`schaltplan_fahrrad_ruecklichtsystem.kicad_sch/.pdf`)** | **09.08.2026** | **Gültiger Zeichnungsstand; ersetzt Schaltplan v2** |
| ~~Schaltplan v2.pdf~~ | 20.05.2026 | **überholt** — an drei Stellen nachweislich falsch, nicht mehr verwenden |
| **Messfahrt-Export `SmartBikeRearLightFahrt202608082245.csv`** | **08.08.2026** | **Feldnachweis Stufe 1, Schema v3, 10 Hz** |
| Feldtest-Exporte 06.08.2026 (sechs CSV, Schema v2, 1 Hz) | 06.08.2026 | Vorher-Vergleich. **Fahrt 5 wurde aus dem fahrenden Auto durchgeführt und ist kein Integritätsnachweis** (Klarstellung des Verfassers 12.08.2026) |
| `Uebersicht.xlsx` (BOM) | 17.02.2026 | Stückliste mit Preisen — korrekturbedürftig (Kap. 11) |
| Datenblätter (ESP32-WROOM-32E, BMP280, GY-521, IRLZ44N, MT3608, TP4056, **Quectel L86 Hardware Design V1.0**, **NTE30180 Rev. 9-21**) | Herstellerstand | Referenzwerte. NTE30180 ist ein **typgleiches Vergleichsbauteil** zur roten Leuchte, die Typidentität mit dem verbauten Teil ist nicht belegt |
| **Angebotsangabe des Händlers zur gelben Leuchte** | abgerufen 12.08.2026 | 590–595 nm, 2,2–2,4 V. **Kein Datenblatt**, die Stromangabe widerspricht sich im Angebot selbst |
| **Schaltplan Rev. 1.3** (`schaltplan_fahrrad_ruecklichtsystem.kicad_sch/.pdf`) | **10.08.2026** | **Gültiger Zeichnungsstand; ersetzt Rev. 1.1** |
| **Fotodokumentation des Aufbaus** (Steckaufbau, handschriftlicher Bestückungsplan, Lochrasterplatine, Einbau im Gehäuse) | 08/2026 | Belegmaterial für Kap. 5.5 und Kap. 8 |
| Nutzer-Lastenheft Firmware | 21.07.2026 | Funktionaler Zielumfang (Kap. 2) |
| § 67 StVZO (Primärtext) / UN-R50, R148, R74, R60 / UN-R53 | 07/2026, geprüft 11.08.2026 | Normative Grundlage (Kap. 2.8). **ECE R6 als nicht einschlägig erkannt.** |
| **§ 23 Abs. 1a StVO** | geprüft 12.08.2026 | Verbot des Aufnehmens und Haltens elektronischer Geräte durch Fahrzeugführende. Grundlage der Bedienkonzeptentscheidung zu FR-SYS-05 (Kap. 2.1 und Kap. 10) |

---

## 1. Projektübersicht

### 1.1 Ziel
Entwicklung eines funktionsfähigen Prototyps eines *Smart Bike Rear Light*. Das System fungiert als IoT-Gerät, das mittels IMU-gesteuerter Bremslichtfunktion, Funk-Blinkern (433 MHz) und einer Live-Datenschnittstelle (BLE → iOS-App) die Verkehrssicherheit und Datenaufzeichnung für Radfahrer verbessert.

### 1.2 Kurzbeschreibung
Ein ESP32 erfasst zyklisch Daten von GNSS (Quectel L86), Barometer (BMP280) und IMU (MPU-6050), steuert ein rotes Schluss-/Bremslicht (PWM) sowie gelbe Funk-Blinker und streamt Live-Telemetrie an eine native iOS-App, die Statistik, Sensorfusion und Visualisierung übernimmt.

### 1.3 MVP
Zuverlässige Sensorerfassung und -Streaming, funktionierendes Schluss-/Bremslicht (intensitätsabhängig), Funk-Blinker, BLE-Live-Anzeige der Basis-Kennzahlen. Details s. Kap. 2.4.

### 1.4 Future Work
Erweiterte Fahranalyse, Sensorfusion, Sicherheitsfunktionen, Pseudo-Leistung/Kalorien, automatische Blinker-Rückstellung, RF-Anlernmodus, GNSS-Warnanzeige, OTA-Updates. Details s. Kap. 2.4.

---

## 2. Anforderungen an die Firmware (SRS) — vollständig (Blöcke A–H)

### 2.0 Kennzeichnung & ID-Systematik
Anforderungs-IDs: `FR-<Subsystem>-NN` (funktional), `NFR-<Kategorie>-NN`, `CON-NN` (Randbedingung), `OUT-NN` (ausgeschlossen).
Subsystem-Kürzel: `SYS`, `TL`, `BLK`, `RF`, `SNS`, `TEL`, `STA`, `SAF`, `CFG`.
NFR-Kategorien: `RT`, `RES`, `PWR`, `TST`, `EXT`.

> **Bearbeitungsstand SRS:** **Alle Blöcke A–H freigegeben — SRS vollständig (21.07.2026).** A (2.1), B (2.6), C (2.7), D (2.6/2.7), E (2.9), F (2.10), G (2.11), H (2.12). Normative Grundlage in 2.8.

### 2.1 Systemgrenzen & Kontext — Block A

| ID | Anforderung | Status |
|---|---|---|
| FR-SYS-01 | Firmware = Datenerfassungs- und Echtzeitknoten. Alle kumulativen/fusionierten Kennzahlen werden in der App berechnet (Variante 2). | gesichert |
| FR-SYS-02 | Firmware liest GNSS, BMP280, MPU6050 zyklisch aus und stellt Rohmesswerte als Telemetrie bereit. | gesichert |
| FR-SYS-03 | Lokal nur echtzeit-/sicherheitsrelevante Größen: Bremslichtintensität aus IMU-Verzögerung, Blinkerzustand. | gesichert |
| FR-SYS-04 | Schnittstelle zur App unidirektional (ESP32 → App); keine Steuerbefehle über BLE. | gesichert |
| FR-SYS-05 | Blinkersteuerung ausschließlich über 433-MHz-Fernbedienung. | gesichert |
| FR-TL-01 | Rote LED = kombiniertes Schluss-/Bremslicht; Grundzustand dauerhaft gedimmtes Schlusslicht. | gesichert |
| FR-TL-02 | Bremslicht-Helligkeit steigt mit der Bremsintensität (Kennlinie FR-TL-06). | gesichert |
| CON-01 | Datensenke = App; Firmware speichert nicht dauerhaft, nur flüchtiger RAM-Ringpuffer (FR-TEL-04). | gesichert |
| OUT-01 | Keine Akkustandsanzeige/Batteriespannungsmessung in HW/FW. | gesichert |
| OUT-02 | Nicht im MVP: Auto-Helligkeit, Standlicht, Auto-Blinker-Rückstellung, Flash-Voll-Logging. | gesichert |

### 2.2 Datenkatalog — Rohmesswerte (Firmware liefert)
- **GNSS (L86):** Position, Geschwindigkeit, Heading, UTC-Zeit, Satellitenanzahl, HDOP, Höhe.
- **BMP280:** Luftdruck, Temperatur.
- **MPU-6050:** Beschleunigung (3 Achsen), Drehrate (3 Achsen).

### 2.3 Datenkatalog — abgeleitete Fahrdaten (App berechnet, FR-SYS-01)
- **aus GNSS:** aktuelle/Durchschnitts-/Höchstgeschwindigkeit, Distanz, Route, Fahrzeit, Bewegungsrichtung, Start-/Zielposition, Zwischenzeiten.
- **aus BMP280:** aktuelle Höhe, Höhenmeter bergauf/bergab, max./min. Höhe, Temperatur, durchschnittl. Steigung.
- **aus MPU:** Bremsvorgänge, Sprints, Kurvenwinkel/-anzahl, Lean Angle, Sturzerkennung, Schräglagen L/R.
- **Sensorfusion:** GNSS+MPU, GNSS+BMP, BMP+MPU, alle drei (Pseudo-Power → Kalorien, Trainingsintensität).

### 2.4 MVP- und Future-Work-Umfang (App-Anzeige)
**MVP:** aktuelle/Durchschnitts-/Maximalgeschwindigkeit, Distanz, Fahrzeit, Höhe, Höhenmeter, Satellitenanzahl, Bluetooth-Status. *(kein Akkustand, OUT-01.)*
**Future-Work:** erweiterte Fahranalyse, Sicherheitsfunktionen, Nice-to-have (Pseudo-Leistung, Kalorien, Höhenprofil, Bremsereignisse, Road-Quality, Fahrstilanalyse), RF-Anlernmodus, OTA.

### 2.5 Eingangs-Lastenheft
Vollständig in den SRS-Blöcken A–H formalisiert. Keine offenen Rohanforderungen mehr.

### 2.6 Zustandsmodell — Block B (+ D-Präzisierungen)
Vier parallele (orthogonale) Regionen (Statechart nach Harel; Diagramme in Kap. 6.6). Kritischer Sensor ist ausschließlich die IMU (MPU6050); GNSS und BMP280 optional.

| ID | Anforderung | Status |
|---|---|---|
| FR-STA-01 | Power-On → INIT. Übergang INIT→RUN, sobald kritische Sensoren (IMU) initialisiert sind oder Init-Timeout 5 s abgelaufen ist. | gesichert |
| FR-STA-02 | Bei Init-Timeout → degradierter RUN: rote LED dauerhaft Schlusslicht (§ 67 gewahrt). | gesichert |
| FR-STA-03 | Regionen 2–4 laufen unabhängig; Sensor-/Systemfehler erzwingt kein regionsübergreifendes Sperren. | gesichert |
| FR-TL-03 | Während INIT signalisiert die rote LED per Diagnose-Blinken (~2 Hz, Zeit-Duty 50 %, moduliert 0 %↔~50 %) die Nicht-Bereitschaft. | gesichert |
| FR-TL-04 | In RUN leuchtet die rote LED dauerhaft mindestens als gedimmtes Schlusslicht (~20 %). | gesichert |
| FR-TL-05 | Bremslicht ist temporäre Helligkeitsanhebung; nach Bremsende Rückfall auf Schlusslicht (Kennlinie FR-TL-06). | gesichert |
| FR-BLK-01 | Richtungsblinker per kurzem Tastendruck (T1=links, T2=rechts); erneuter kurzer Druck = aus (Toggle). | gesichert |
| FR-BLK-02 | Umschalten Links↔Rechts durch andere Taste; setzt 60-s-Timeout neu. | gesichert |
| FR-BLK-03 | Richtungsblinker: max. Blinkdauer 60 s → automatische Selbstabschaltung. | gesichert |
| FR-BLK-04 | Warnblinker durch Langdruck (≥ 5 s) einer beliebigen Taste; beide Seiten blinken; kein Timeout. | gesichert |
| FR-BLK-05 | Warnblinker endet durch beliebigen einzelnen kurzen Tastendruck → AUS. | gesichert |
| FR-BLK-06 | Links/Rechts gegenseitig verriegelt; WARN einziger Zustand mit beidseitigem Blinken. | gesichert |
| FR-BLK-07 | Kurz-/Langdruck-Diskriminierung: Loslassen < 5 s = Kurzdruck; Halten ≥ 5 s = Warnblinker. | gesichert |
| FR-BLK-09 | RF-Blinkerbefehle werden erst ab RUN wirksam; während INIT verworfen. | gesichert |
| FR-SNS-01 | Ab RUN werden GNSS, BMP280, MPU6050 zyklisch gesampelt — unabhängig vom BLE-Zustand. | gesichert |
| FR-TEL-01 | Bei BLE-Verbindung Telemetrie-Stream; ohne Verbindung RAM-Ringpuffer (FR-TEL-04). | gesichert |

### 2.7 Funktionale Detaillogik — Block C

| ID | Anforderung | Status |
|---|---|---|
| FR-TL-06 | Bremslicht-Kennlinie: Schlusslicht-Grundhelligkeit ~20 % PWM. Stetig-linearer Anstieg von 2,0 m/s² bis Sättigung 5,0 m/s² (100 %). Ausschalthysterese: Rückfall unter ~1,5 m/s². Mindesthaltezeit 300 ms. Anstieg schnell (Sicherheit). Eingang: gravitationskompensierte Längsverzögerung aus `motion_filter`. Norm-Anker ECE R50 (§ 67 Abs. 4). **Stand 09.08.2026:** Proportionalkennlinie bench- **und** feldvalidiert (Kap. 9.3/9.5; im Feld 194 von 194 Zeilen auf ±1 Prozentpunkt). Die Eingangsgröße ist seit Stufe 1 feldverifiziert (Kap. 9.5). **Die Mindesthaltezeit ist im Fahrbetrieb nachweislich unwirksam** — Mangel M-01, Kap. 9.5.4. | Kennlinie gesichert · Eingangsgröße feldverifiziert · **Mindesthaltezeit: Anforderungsabweichung** |
| FR-TL-07 | Notbrems-Blinken (ESS-Konzept): aktiviert ab ≥ 5,0 m/s², deaktiviert bei < 3,0 m/s². ~4 Hz, Zeit-Duty 50 %. **Experimentalfunktion, standardmäßig DEAKTIVIERT — nicht konform mit § 67 Abs. 4 StVZO.** | gesichert (experimentell) |
| FR-BLK-08 | Blinkfrequenz 1,5 Hz, Duty 50 %, Hellzeit > 0,3 s. **Normbezug korrigiert 11.08.2026:** Der Wert entspricht den 90 ± 30 Impulsen je Minute aus UN-R53 § 6.3.8.1. Die frühere Angabe ECE R6 war nicht verifiziert und ist nicht einschlägig. R53 gilt für Krafträder, der Wert wird deshalb als **Analogie** übernommen, begründet über die Wiedererkennbarkeit des Signalbilds. | gesichert · Normbezug als Analogie |
| CON-02 | PWM-Trägerfrequenz aller LED-Kanäle 5 kHz, 8 bit Auflösung. | gesichert |
| FR-RF-01 | Kontinuierliche Überwachung GPIO4 (RCSwitch); nur bekannte Codes (T1=10967538, T2=10967537). | gesichert |
| FR-RF-02 | Druck erst nach ≥ 2 identischen Empfängen gültig (Entprellung/EMV). | gesichert |
| FR-RF-03 | Halte-Erkennung; „losgelassen" nach Empfangslücke > Release-Timeout (~150 ms, final nach Verifikationstest). | gesichert |
| FR-RF-04 | Kurzdruck (< 5 s) → SHORT; Halten ≥ 5 s → LONG (Warnblinker). | gesichert |
| FR-RF-05 | Reaktionszeit erkanntes Ereignis → LED < 100 ms. | gesichert |
| FR-RF-06 | RF-Codes fest im Code; Anlern-/Pairing-Modus → Future-Work. | gesichert |
| FR-SNS-02 | Sampling: IMU 100 Hz, BMP280 10 Hz, GNSS 1 Hz (ab RUN, unabhängig von BLE). | gesichert |
| FR-TEL-02 | Telemetrie-Frame 10 Hz, frischeste Werte + Status. | gesichert |
| FR-TEL-03 | Frame-Inhalt: IMU, BMP, GNSS, Status; ab Schema v3 zusätzlich GNSS-Referenzbeschleunigung, Filter-Innensicht und 100-Hz-Fensteraggregate. Kein Akkustand. | gesichert |
| FR-TEL-04 | Ohne BLE Pufferung im RAM-Ringpuffer; Überlauf überschreibt Ältestes. | gesichert |

### 2.8 Normative Grundlagen der Lichtfunktionen [am Primärtext geprüft 11.08.2026]

| Norm | Gegenstand | Bezug im Projekt |
|---|---|---|
| § 67 Abs. 1 StVZO | nur bauartgenehmigte lichttechnische Einrichtungen (§ 22a) | Prototyp **nicht** bauartgenehmigt |
| § 67 Abs. 2 Satz 5 StVZO | Kombinationsverbot für Fahrtrichtungsanzeiger | FR-BLK-* |
| § 67 Abs. 3 StVZO | Scheinwerfer: Blinken unzulässig | – |
| § 67 Abs. 4 StVZO | Rote Schlussleuchte; Bremslichtfunktion **ausdrücklich erlaubt** (Verweis auf UN-R50); blinkende Schlussleuchten unzulässig | FR-TL-01/04/06 konform; **FR-TL-07 Konflikt** |
| § 67 Abs. 5 StVZO | Fahrtrichtungsanzeiger **zulässig**, sofern nach UN-R50 oder UN-R148 genehmigt, nach UN-R74 angebaut und Bedienteile nach UN-R60 angeordnet | FR-BLK-*; Prototyp erfüllt keine der drei Bedingungen |
| UN-R50 / UN-R148 | Genehmigung von Schluss-, Brems- und Fahrtrichtungsleuchten | von § 67 in Bezug genommen |
| UN-R74 / UN-R60 | Anbau bzw. Anordnung der Bedienteile | von § 67 in Bezug genommen |
| UN-R53 § 6.3.8.1 (Krafträder) | Blinkfrequenz 90 ± 30/min = 1,5 Hz ± 0,5 | FR-BLK-08 — **Analogie**, gilt nicht für Fahrräder |
| UN-R53 § 6.14.7.1 (Krafträder) | Notbremssignal 4,0 ± 1,0 Hz | FR-TL-07 — **Analogie** |
| UN-R13-H (Pkw) | Signalisierungsschwelle 1,3 m/s²; Hysterese gegen Flackern gefordert, Wert nicht geregelt | FR-TL-06 — **Analogie** |

**Korrektur 11.08.2026.** Die bis v0.20 geführte Referenz **ECE R6 ist nicht einschlägig**. Sie betrifft Fahrtrichtungsanzeiger an Kraftfahrzeugen und wird von § 67 StVZO nicht in Bezug genommen. Sie ist durch die oben genannten Regelungen ersetzt.

**Zwei Feststellungen mit Bedeutung für die Thesis.** Erstens erlaubt § 67 Abs. 4 StVZO die Bremslichtfunktion an der Schlussleuchte ausdrücklich; das Vorhaben steht damit auf einer positiven Rechtsgrundlage und ist keine Grauzone. Zweitens lässt § 67 Abs. 5 StVZO Fahrtrichtungsanzeiger am Fahrrad ausdrücklich zu. Eine Einschränkung auf mehrspurige Fahrräder enthält der Wortlaut nicht. Die gegenteilige Aussage in `Parameterherleitung.md`, Abschnitt 13, ist falsch und dort zu korrigieren.

**Quantitative Vorgaben macht § 67 StVZO nicht.** Weder Verzögerungsschwellen noch Haltezeiten, Reaktionszeiten oder Lichtstärken sind dort geregelt; die photometrischen Anforderungen sind über § 22a in die Bauartgenehmigung verlagert. Jeder normative Bezug auf eine UN-Regelung in diesem Projekt ist deshalb eine ingenieurtechnische Analogie und keine Rechtsgrundlage. Das ist in der Arbeit an jeder Stelle so zu kennzeichnen.

### 2.9 Fehlerbehandlung & Sicherheit — Block E

| ID | Anforderung | Status |
|---|---|---|
| FR-SAF-01 | Fail-safe-Leitprinzip: Bei jedem erkennbaren Fehler bleibt das rote Schlusslicht an (§ 67). | gesichert |
| FR-SAF-02 | Funktionspriorität: Schlusslicht > Bremslicht > Blinker > Telemetrie. | gesichert |
| FR-SAF-03 | Task-Watchdog (~2 s), Reset bei Hang; Reset-Ursache als Diagnose-Flag. | gesichert |
| FR-SAF-04 | BLE-/Telemetrie-Fehler dürfen Licht/Blinker nicht beeinträchtigen. | gesichert |
| FR-STA-04 | Laufzeit-IMU-Ausfall → sicheres Schlusslicht, Fehler-Flag, Hintergrund-Reinit. | gesichert |
| FR-STA-05 | Ausfall optionaler Sensoren → Weiterbetrieb, Telemetriefelder ungültig markiert. | gesichert |
| FR-STA-06 | Kein harter FAULT im MVP; degradierter RUN mit Fehler-Flags. | gesichert |
| FR-SNS-03 | I²C-Zugriffe zeitbegrenzt (~25–50 ms), nicht-blockierend. | gesichert |
| FR-SNS-04 | Gestufte, nicht-blockierende I²C-Recovery. | gesichert |
| FR-SNS-05 | Leichte Plausibilitätsprüfung (Wertebereich + Eingefroren-Erkennung). | gesichert |
| FR-TEL-05 | GNSS-Status NO_DATA/NO_FIX/FIX_OK; Fix gültig wenn isValid & Alter < 3 s & Sats ≥ 4. | gesichert |

### 2.10 Nichtfunktionale Anforderungen — Block F

| ID | Anforderung | Status |
|---|---|---|
| NFR-RT-01 | Bremslicht-Reaktionszeit ≤ 50 ms (Ereignis → LED). | **erfüllt** (Bench: ≤ 10 ms, Kap. 9.3) |
| NFR-RT-02 | Blinktakt 1,5 Hz timer-basiert; Periodentoleranz ± 5 %. | gesichert |
| NFR-RT-03 | Kooperativer, nicht-blockierender Scheduler; IMU/Bremslicht 100 Hz. | gesichert |
| NFR-RT-04 | Worst-Case-Loop-Durchlauf < 10 ms. | **erfüllt, aber knapper als angenommen:** Fahrbetrieb 6,7 ms (Kap. 9.5.5), Prüfstand 0,651 ms |
| NFR-RES-01 | RAM-Ringpuffer ~60 s @ 10 Hz (≈ 600 Frames), statisch vorreserviert. | gesichert |
| NFR-RES-02 | Keine dynamische Speicherallokation im Betrieb. | gesichert |
| NFR-RES-03 | RAM-/CPU-Auslastung gemessen und dokumentiert. | gesichert |
| CON-03 | Flash-Partition „No OTA / große App"; Konfig über NVS/`Preferences`. | gesichert |
| NFR-PWR-01 | WiFi aus (nur BLE); kein Deep/Light-Sleep im MVP. | gesichert |
| NFR-PWR-02 | **Zielaufzeit rund 8 h** im Dauerbetrieb mit Schlusslicht (rechnerisch, Kap. 5.2). Die frühere Angabe von ~13 h beruhte auf einer methodisch fehlerhaften Bilanz und ist zurückgezogen. Messtechnische Verifikation weiterhin offen. | **korrigiert 09.08.2026** |

### 2.11 Konfigurierbarkeit — Block G

| ID | Anforderung | Status |
|---|---|---|
| FR-CFG-01 | Alle Kalibrier- und Strukturwerte sind benannte Konstanten in `include/config.h`, keine Magic Numbers im Code: Bremsschwellen, Mindesthaltezeit, GNSS-Fix-Kriterien, Aktivierungs-Flag FR-TL-07, Pinbelegung, PWM-Frequenz, Blinkfrequenz, Timeouts, RF-Codes, Sampling-/Telemetrie-Raten, **Einbaulage der IMU (Kap. 4.3)**. | **erfüllt** — Umsetzung als Übersetzungszeit-Konstanten statt zur Laufzeit; Änderung erfordert Neuübersetzung |
| FR-CFG-02 | Serielles Kalibrier-/Konfigurations-Interface über UART0, nicht-blockierend. | **abgegrenzt (10.08.2026)** — nicht umgesetzt, Begründung Kap. 12.2 |
| FR-CFG-03 | Bei leerem/fehlendem NVS Compile-Zeit-Defaults; `config_version`-Schlüssel. | **abgegrenzt (10.08.2026)** — nicht umgesetzt, Begründung Kap. 12.2 |

### 2.12 Testbarkeit & Erweiterbarkeit — Block H

| ID | Anforderung | Status |
|---|---|---|
| NFR-TST-01 | Strikte Trennung reine Logik ↔ Hardware-Treiber; Logik host-seitig testbar. | gesichert |
| NFR-TST-02 | Testdaten-Einspeisung als schlanker Hook. | gesichert |
| NFR-TST-03 | Zwei Test-Ebenen: Host-Unit-Tests (Unity/PlatformIO `native`) und On-Target-Validierung. | gesichert |
| NFR-EXT-01 | Modulare Struktur mit klaren Schnittstellen. | gesichert |
| FR-TEL-06 | Telemetrie-Frame trägt eine Schema-/Versionskennung. | gesichert (aktuell Schema v3, 113 Byte) |

### 2.13 Konstruktive Anforderungen — Block K [neu, 11.08.2026]

Dieser Block stand **nicht** am Anfang der Entwicklung. Die konstruktiven Anforderungen wurden abgeleitet, nachdem der Aufbau der Elektronik feststand. Erst mit festgelegter Bauteilauswahl, Verschaltung und Strombilanz war bestimmbar, welchen Bauraum, welche Zugänglichkeiten und welche thermischen Randbedingungen ein Gehäuse erfüllen muss. Das Vorgehen ist bewusst so dokumentiert und in der Thesis auch so darzustellen.

Für diese Gruppe wird zusätzlich zwischen **Forderung (F)** und **Wunsch (W)** unterschieden, angelehnt an die Anforderungsliste nach VDI 2221. Für die übrigen Blöcke gilt diese Unterscheidung nicht.

| ID | Anforderung | Art | Grundlage |
|---|---|---|---|
| KON-01 | Alle Baugruppen sind in einem geschlossenen Gehäuse unterzubringen. Die Außenmaße folgen aus der Anordnung der Elektronik. | F | Bauteilübersicht Kap. 4.1 |
| KON-02 | Der Ladeanschluss (USB-C an U1) muss von außen zugänglich sein, ohne das Gehäuse zu öffnen. | F | Kap. 4.1 |
| KON-03 | Der Ein- und Ausschalter SW1 muss von außen bedienbar sein. | F | Kap. 4.1 |
| KON-04 | Der Programmieranschluss des DevKitC ist im montierten Zustand bewusst nicht zugänglich. | F | Kap. 4.1 |
| KON-05 | Die Antenne des GNSS-Moduls benötigt freie Sicht nach oben und ein nichtmetallisches Gehäuse im Antennenbereich. | F | L86-Datenblatt, Kap. 8 |
| KON-06 | Der Gehäusewerkstoff muss die Wärmeentwicklung der Vorwiderstandsnetze RN1–RN3 und der Transistoren Q1–Q3 ertragen, ohne sich zu verformen. | F | Kap. 5.4 |
| KON-07 | Die Verbindungstechnik muss wiederholtes Öffnen und Schließen ohne Festigkeitsverlust erlauben. | F | Kap. 8 |
| KON-08 | Die Lichtaustrittsflächen müssen so angeordnet sein, dass die rote Leuchte nach hinten und die beiden gelben Leuchten als Richtungsanzeige erkennbar wirken. | F | Funktion, FR-TL-01, FR-BLK-* |
| KON-09 | Die innere Kabelführung soll definiert sein und die Montage nicht behindern. | W | Kap. 8 |
| KON-10 | Das Gehäuse soll fertigungsgerecht für das FDM-Verfahren gestaltet sein. | W | Kap. 8 |

**Systemgrenze Trockenbetrieb [festgelegt 11.08.2026].** Für das System wurden **keine Umgebungsanforderungen** festgelegt. Weder ein Temperaturbereich noch ein Schutz gegen Feuchtigkeit oder Spritzwasser sind spezifiziert, und ein entsprechender Nachweis wurde nicht geführt. Der Prototyp ist damit ausdrücklich für den **Trockenbetrieb** ausgelegt. Ein dichtes Gehäuse ist für ein Serienprodukt erforderlich und wird als Ausblick geführt. Diese Festlegung ersetzt die bisher unausgesprochene Annahme einer Outdoor-Tauglichkeit.

**Anzahl der Anforderungen insgesamt:** 79 eindeutige Einträge — 51 FR, 13 NFR, 10 KON, 3 CON, 2 OUT.

**Offen:** Die konkreten Maße, Wandstärken, Druckparameter und die Befestigungsart am Fahrrad sind nicht Teil der Anforderungen, sondern Ergebnis der Konstruktion und in Kap. 8 der Thesis dokumentiert.

**Geschlossen 17.08.2026 — Nachweisart je Anforderung.** Für jede der 79 Anforderungen ist die Nachweisart festgelegt. Vier Arten: **Analyse** (Rechnung), **Inspektion** (Sichtprüfung von Aufbau oder Umsetzung), **Test** (Prüffall auf dem Entwicklungsrechner oder am Gerät), **Messung** (Messwert aus Kap. 9). Zusätzlich gilt eine vierstufige Bewertung des Erfüllungsgrads: *erfüllt und nachgewiesen*, *erfüllt, nicht nachgewiesen*, *teilweise erfüllt*, *bewusst abgegrenzt*. Für die beiden Ausschlüsse OUT-01 und OUT-02 gilt *eingehalten*. Die vollständige Matrix ist Anhang B der Thesis.

**Bewertungsstand 17.08.2026:** 73 der 79 Anforderungen sind erfüllt und nachgewiesen. Eingeschränkt sind sechs: FR-TL-06 (Mindesthaltezeit behoben, aber nicht im Feld nachgemessen), FR-TL-07 (umgesetzt, dauerhaft abgeschaltet), FR-CFG-02 und FR-CFG-03 (bewusst abgegrenzt), NFR-PWR-02 (gerechnet, nicht gemessen), KON-06 (Werkstoffwahl aus der gerechneten Verlustleistung, keine Temperaturmessung).

**Lücke im Anforderungsbestand [neu 17.08.2026].** Für die Funkstrecke ist keine Anforderung an die Erkennungsrate spezifiziert, obwohl sie die einzige Eingabeschnittstelle des Systems ist. Die in Kap. 9.6 gemessenen 92,5 % sind damit ein Eigenwert ohne zugehörige Sollvorgabe. Die Lücke ist eine fehlende Anforderung und keine verfehlte. Bei einer Fortführung ist sie zu ergänzen, zusammen mit einer Rückmeldung am Lenker.

---

## 3. Gesamtsystem

### 3.1 Architektur (Variante 2 — verteilte Berechnung)
```
[Sensorik]                [ESP32 Firmware]                 [iOS-App]
 GNSS L86  ─UART2─┐        ┌───────────────────────┐       ┌────────────────────┐
 BMP280    ─I²C──┼──────▶ │ Erfassung + Echtzeit-  │──BLE─▶│ Statistik, Fusion, │
 MPU6050   ─I²C──┘        │ logik (Bremse/Blinker) │ (uni) │ Speicherung, UI    │
 433-MHz-RX ─GPIO4──────▶ │ + Telemetrie-Stream    │       └────────────────────┘
                          └─────────┬──────────────┘
                                    │ PWM (GPIO25/26/27)
                            [Aktorik: rote + gelbe LEDs über IRLZ44N]
```

### 3.2 Datenflüsse
Sensor-Rohdaten → Firmware (Sampling FR-SNS-02) → (a) echtzeitkritische Ableitung Bremse/Blinker → LED; (b) Telemetrie-Serialisierung (10 Hz, versioniert) → BLE-Notify → App. Steuerrichtung App→ESP32 existiert nicht (FR-SYS-04).

### 3.3 Schnittstellen
I²C (Sensoren), UART2 (GNSS), UART0 (Debug/Konfig), digitaler GPIO-Eingang (RF), PWM-Ausgänge (LEDs, 5 kHz), BLE (Telemetrie → App).

---

## 4. Hardware

### 4.1 Bauteilübersicht [Stand 09.08.2026, vollständig gegen den realen Aufbau geprüft]

| Ref. | Bauteil | Hersteller/Typ | Funktion | Versorgung / Schnittstelle | Status |
|---|---|---|---|---|---|
| U3 | **Espressif ESP32-DevKitC-32E (WROOM-32E)** | Espressif | Hauptrechner, AMS1117-3.3 onboard | VIN 5 V → 3V3 | Board-Tausch ausgeführt und validiert (`docs/ble_brownout_fallstudie.md`). **Ersetzt** das ursprünglich verbaute **AZ-Delivery ESP-32 Dev Kit C V2** (Anleitung AZ281). **Beide Boards tragen denselben Reglertyp AMS1117-3.3**; der Brownout war damit keine Eigenschaft des Reglertyps, sondern eine Grenze oder ein Defekt des konkreten Altboards |
| IC2 | MPU-6050 (GY-521) | AZ-Delivery | IMU | **+3V3**, I²C 0x68 (AD0 modulseitig auf GND) | validiert |
| IC3 | BMP280 | AZ-Delivery | Barometer | **+3V3**, I²C 0x76 | validiert |
| IC4 | Quectel L86-M33 | Quectel | GNSS. **Empfang von GPS und GLONASS auf L1** (Datenblatt Tab. 1). SBAS und QZSS werden zusätzlich unterstützt, am Einsatzort ist davon **nur SBAS in Form von EGNOS wirksam**, weil QZSS ein regionales System über Asien und Ozeanien ist | **+3V3** an VCC **und** V_BCKP, UART 9600 Bd | validiert (Feldfix erreicht) |
| U4 | SRX882S V2.0 | NiceRF | **Empfangsseite.** 433-MHz-Überlagerungsempfänger für ASK/OOK. Datenblatt Rev. V1.0 seit 11.08.2026 abgelegt: f = 433,92 MHz typ., Bandbreite 200 kHz, Empfindlichkeit **−107 dBm** bei 1 kbit/s, 0,1–9,6 kbit/s, 2,0–5,5 V, < 3 mA im Betrieb, < 0,1 µA bei CS = 0, Einschaltzeit < 3 ms | **+3V3** an VCC **und** CS, DATA → GPIO4 | validiert |
| — | QIACHIP-Fernbedienung (2 Tasten), Codierbaustein PT2262 | QIACHIP | **Sendeseite, Kaufteil.** Blinkerauslösung. Die früher als Widerspruch geführte Doppelbezeichnung „SRX882S vs. PT2262" ist damit aufgelöst: PT2262 sitzt im Handsender, SRX882S ist der Empfänger im Gerät. Konformität der Sendeparameter beruht auf der CE-Kennzeichnung, ein eigener Nachweis wurde nicht geführt | eigene Batterie, 433 MHz ASK | validiert (10967538 / 10967537) |
| Q1–Q3 | IRLZ44N (3×) | Int. Rectifier | Low-Side-PWM-Treiber | Gate an GPIO über 100 Ω | validiert |
| R1/R3/R5 | 100 Ω (3×) | – | Gate-Serienwiderstand | – | verbaut |
| ~~R2/R4/R6~~ | ~~10 kΩ (3×)~~ | – | ~~Gate-Pull-Down gegen GND~~ | – | **nicht bestückt (Korrektur 13.08.2026).** Schaltplan Rev. 1.3 führt das als Befund B-9. Die frühere Angabe „real verbaut" aus der Projektanalyse vom 21.07.2026 ist damit überholt |
| RN1–RN3 | je 8 × 100 Ω parallel = 12,5 Ω | – | Strombegrenzung je LED-Kanal | in Reihe zur LED | verbaut |
| D1 | **LED rot, 3 W** | Vrabocry | Schluss- + Bremslicht (GPIO26) | Anode an **+5 V**, PWM über Q2 | **Bestückung geklärt 09.08.2026.** Kennwerte nach typgleichem Vergleichsbauteil NTE30180-R: Dauerstrom 800 mA, V_f 2,0–2,6 V bei 400 mA, 620–630 nm, 90 lm typ. bei 800 mA, T_J typ. 115 °C gegen Grenzwert 120 °C |
| D2/D3 | **LEDs gelb, 3-W-COB** | Vrabocry | Blinker links/rechts (GPIO25/27) | Anode an **+5 V**, PWM über Q1/Q3 | **Bestückung geklärt 09.08.2026** |
| U1 | TP4056 Typ-C (DW01) | – | LiPo-Laderegler 1 A | USB-C, von außen zugänglich | verbaut; Verhalten unter Last unverifiziert |
| U2 | MT3608 Step-Up | AZ-Delivery | 3,7 V → 5,00 V (Trimmer) | von U1 OUT+ | verbaut; unter Last nicht abgeglichen |
| BT1 | LiPo-Akku LP103454, 3,7 V, 2000 mAh | – | Energiespeicher | B+/B− an U1 | verbaut |
| SW1 | **Wippschalter KCD1-2** | – | Ein/Aus | **im Akkupfad zwischen U1 OUT+ und U2 VIN+**; trennt den Eingang des Wandlers, dadurch ist die gesamte +5-V-Schiene stromlos | verbaut. **Korrektur 13.08.2026:** bis v0.22 als rastender Drucktaster IP65 geführt, tatsächlich ein Wippschalter. Das Typenschild nennt 6 A / 250 V AC und 10 A / 125 V AC; eine **Gleichstromangabe fehlt**, Befund B-6 bleibt offen |
| C1 | Elko 1000 µF | – | Pufferung Reglereingang | +5 V ↔ GND | verbaut |
| C2 | Elko 1000 µF | – | Pufferung Reglerausgang | +3V3 ↔ GND | verbaut |
| ~~ANT2~~ | ~~Drahtantenne 17,3 cm (λ/4)~~ | – | – | – | **nicht verbaut (verbindlich festgelegt 12.08.2026).** U4 ANT ist unbeschaltet, der Empfang erfolgt über die Anschlussflächen des Moduls. Das weicht von der Herstellervorgabe einer 50-Ω-Antenne ab. Die Beobachtung, dass der Empfang **mit** Draht schlechter war, bleibt bestehen und ist unerklärt. Aus der BOM zu streichen |
| ~~ANT1~~ | ~~GNSS-Antenne Namvo~~ | Namvo | – | – | **nicht verbaut.** Der L86 nutzt seine interne Patch-Antenne (18,4 × 18,4 × 4 mm); EX_ANT ist unbeschaltet. Aus der BOM zu streichen. |

**Anmerkungen.** Alle drei LED-Kanäle sind mit dem 3-W-Bauteil bestückt und werden bewusst mit **208 bis 240 mA (Rechenwert 224 mA)** statt des Dauerstroms von **800 mA** betrieben (thermische Reserve im gedruckten Gehäuse, Werkstoff PETG — s. Kap. 8). **Korrektur 13.08.2026:** Bis v0.22 stand hier ein Nennstrom von 400–500 mA. Das Datenblatt des typgleichen Vergleichsbauteils nennt 800 mA Dauerstrom, die Reduktion ist also stärker als bisher dokumentiert. Sie ist zugleich die Voraussetzung für den Einbau in ein geschlossenes Kunststoffgehäuse, weil die Sperrschichttemperatur bei Dauerstrom mit typisch 115 °C nur 5 K unter dem Grenzwert liegt. Sämtliche Peripheriemodule liegen an +3,3 V; dadurch ist an keiner Schnittstelle eine Pegelwandlung erforderlich. Der Micro-USB-Anschluss des DevKitC dient ausschließlich der Programmierung und ist im montierten Zustand nicht zugänglich; beim Flashen wird der Akkupfad getrennt.

### 4.2 Pinbelegung [gesichert]

| Signal | GPIO | Zielgerät | Bewertung |
|---|---|---|---|
| SDA | GPIO21 | BMP280 + MPU6050 | gesichert |
| SCL | GPIO22 | BMP280 + MPU6050 | gesichert |
| UART2 RX | GPIO16 | L86 TXD1 (Pin 2) | gesichert |
| UART2 TX | GPIO17 | L86 RXD1 (Pin 1) | gesichert |
| RF DATA | GPIO4 | SRX882S DATA | gesichert |
| Blinker links | GPIO25 | Q1 Gate | gesichert |
| Bremslicht (PWM) | GPIO26 | Q2 Gate | gesichert |
| Blinker rechts | GPIO27 | Q3 Gate | gesichert |
| Gate-Widerstand | 100 Ω | alle 3 Gates | gesichert |
| ~~Gate-Pull-Down~~ | ~~10 kΩ → GND~~ | – | **nicht bestückt**, s. Kap. 4.1 und Befund B-9 |

Der MPU6050-INT-Pin bleibt unbeschaltet (GPIO4 durch RF belegt) → Polling. Die Strapping-Pins GPIO0, 2, 5, 12 und 15 sind frei. GPIO16/17 sind beim WROOM-32E ohne Einschränkung nutzbar (die bekannte PSRAM-Belegung betrifft nur WROVER-Module). Pinbelegung im Code: `firmware/include/pins.h`.

**I²C-Bus-Initialisierung [gesichert]:** `Wire.begin(SDA,SCL)` + `Wire.setTimeOut(I2C_TIMEOUT_MS)` erfolgen zentral einmalig in `main.cpp`/`setup()`. `imu_driver` und `bmp280_driver` sind reine Bus-Nutzer. Pull-Up-Widerstände existieren ausschließlich modulintern gegen +3,3 V.

### 4.3 Einbaulage der IMU [umgesetzt und geflasht 10.08.2026]

Die Lochrasterplatine wurde am 09.08.2026 um **180° in ihrer eigenen Ebene** gedreht verbaut (Rotation R_z(180°)). Damit kehren sich die Vorzeichen von a_x, a_y, ω_x und ω_y um; a_z und ω_z bleiben unverändert. Die Y-Achse des Sensors zeigt seitdem **in** Fahrtrichtung statt entgegen.

**Konsequenz ohne Gegenmaßnahme:** Die Bremserkennung kehrt sich um — Bremsen erzeugt kein Bremslicht, Beschleunigen dagegen schon. Der Fehler ist am Schreibtisch nicht auffällig, weil Boot, I²C-Scan, Telemetrie und Regime-Klassifikation unverändert korrekt erscheinen.

**Umgesetzte Lösung [gesichert, Commit `835c7b3`]:** Die Einbaulage ist als Transformation an der Hardware-Abstraktionsgrenze abgebildet, nicht als Vorzeichen in der Auswertelogik. `config.h` führt `IMU_MOUNT_SIGN_X = −1`, `IMU_MOUNT_SIGN_Y = −1` und `IMU_MOUNT_SIGN_Z = +1`; das hardwarefreie Modul `lib/logic/imu_mount_orientation.h` wendet sie in `imuRead()` (`lib/drivers/imu_driver.cpp`) auf Beschleunigung **und** Drehrate an. `MOTION_BRAKE_SIGN` bleibt bei +1. Damit sieht die gesamte nachgelagerte Kette — Filter, Kennlinie, Telemetrie, App, Golden-Vektor, alle Host-Tests — exakt die validierten Signale.

**Warum `MOTION_BRAKE_SIGN` unverändert bleibt.** Die Vorzeichenkonvention wurde vor dem Umbau am realen Board an den Rohdaten verifiziert (Bremsen erzeugt einen positiven Wert der gravitationskompensierten Y-Beschleunigung). Die Rotation kehrt das Rohsignal um, die Transformation stellt es wieder her — die Auswertelogik sieht danach dieselbe Konvention wie vor dem Umbau. Ein zweites Vorzeichen in `motion_filter` wäre eine Doppelanwendung und würde die Bremserkennung erneut invertieren.

**Warum an der Treibergrenze und nicht in der Auswertelogik.** Die Einbaulage ist eine mechanische Eigenschaft des Aufbaus, keine Eigenschaft des Auswerteverfahrens. Wird sie am Übergang Hardware → Logik zurückgerechnet, bleibt jeder nachgelagerte Baustein unverändert gültig: die 126 Host-Tests, der Golden-Vektor, das Telemetrie-Frame und die App-Seite mussten nicht angefasst werden. Ein Vorzeichen in `motion_filter` hätte dagegen nur den Bremspfad korrigiert und Nick- und Querachse gespiegelt gelassen.

**Zwingende Randbedingung:** Die Transformation muss eine echte Rotation mit Determinante +1 sein. Würde nur a_y negiert und ω_x unverändert gelassen, gälte dθ/dt = ω_x nicht mehr; der Komplementärfilter integrierte die Nickschätzung dann in die falsche Richtung. Das wäre am Schreibtisch unsichtbar, weil ω_x im Stand null ist.

**Absicherung.** Der Host-Test `test/test_imu_mount_orientation/` prüft die Transformation isoliert. Am Gerät ist der Umbau im Normalbetrieb geprüft: Boot, Schlusslicht, Bremslichtauslösung und Telemetrie verhalten sich unauffällig; eine Bremsung erzeugt Bremslicht, eine Beschleunigung nicht.

**Referenzwerte für einen späteren Abgleich** (aus der Messfahrt 08.08.2026, aufgenommen im Zustand **vor** dem Umbau — eine systematische Nachmessung ist nach dem Umfangsschnitt vom 10.08.2026 nicht mehr Teil der Arbeit, s. Kap. 12.2):

| Prüfung | Sollwert |
|---|---|
| Ruhelage, eben | a_z ≈ +9,81 m/s²; a_x, a_y ≈ 0 |
| Hinterrad um 10° anheben | transformiertes a_y ≈ **+**1,70 m/s² |
| Ruhezustand auf dem Rad, nach Verankerung | `pitch_rad` ≈ **−4,42°** (Referenzwert der Messfahrt 08.08.2026) |
| Gyro-Nullpunkt nach Kalibrierung | ≈ **−4,08 °/s** (Referenzwert der Messfahrt 08.08.2026) |

**Zwingende Randbedingung, geprüft:** Determinante der Transformation = (−1)·(−1)·(+1) = **+1**. Das Koordinatensystem bleibt rechtshändig, dθ/dt = ω_x gilt unverändert. Wäre nur a_y negiert worden, integrierte der Komplementärfilter die Nickschätzung in die falsche Richtung — ein Fehler, der am Schreibtisch unsichtbar bliebe, weil ω_x im Stand null ist.

---

## 5. Elektronik & Stromversorgung

### 5.1 Topologie [Stand 09.08.2026]

```
USB-C (Buchse auf U1) → TP4056 (1 A Ladung, DW01) ─ B+/B− → LiPo LP103454, 3,7–4,2 V
                                   │ (über OUT+, NICHT B+)
                                   ▼
                                 SW1  (Ein/Aus, im Akkupfad)
                                   ▼
                          MT3608 Step-Up (Trimmer 5,00 V)
                                   ▼
                        ┌──────── +5 V ────────┐
                        │                      │
              ESP32 VIN (U3)            LED-Zweige D1/D2/D3
                        │                (je RN = 12,5 Ω, Low-Side über Q1–Q3)
              AMS1117-3.3 onboard
                        ▼
                     +3,3 V  →  IC2, IC3, IC4 (VCC + V_BCKP), U4 (VCC + CS)
```

Pufferung: C1 = 1000 µF an +5 V ↔ GND (Reglereingang), C2 = 1000 µF an +3V3 ↔ GND (Reglerausgang). Beide ursprünglich als Gegenmaßnahme zum BLE-Brownout verlötet, dort ohne Wirkung (Root Cause = Regler des Altboards, durch Board-Tausch behoben); sie bleiben als Bestandteil eines robusten Versorgungsdesigns verbaut.

SW1 sitzt im Akkupfad **vor** dem Aufwärtswandler und trennt dessen Eingang. Im ausgeschalteten Zustand ist damit die gesamte 5-V-Schiene einschließlich der LED-Zweige stromlos, und zusätzlich entfällt der Ruhestrom des MT3608. Der Ladepfad USB-C → U1 → BT1 bleibt davon unberührt — das Gerät lädt also auch ausgeschaltet. Elektrische Konsequenz der Position: Der Schalterstrom fließt auf der Akkuseite und ist deshalb bei gleicher Leistung höher als auf der 5-V-Seite (Befund B-6).

### 5.2 Energiebilanz [korrigiert 09.08.2026 · rechnerisch, nicht gemessen]

> **Korrekturhinweis.** Die Bilanz der Versionen bis 0.16 addierte Ströme aus der 3,3-V- und der 5-V-Domäne und teilte die Summe durch eine bei 3,7 V geltende Kapazität. Das ist methodisch unzulässig. Zusätzlich war der LED-Strom mit 50 mA um den Faktor 4,5 zu niedrig angesetzt. Die daraus abgeleiteten ~13 h sind zurückgezogen.

Grundlage: I_LED = (5 V − V_f)/12,5 Ω. Mit V_f = 2,0 bis 2,4 V ergibt sich eine Spanne von **208 bis 240 mA** je Kanal, als Rechenwert wird **224 mA** bei V_f = 2,2 V geführt [belegte Spanne aus NTE30180-R und der Angebotsangabe zur gelben Leuchte, Einzelwert weiterhin Annahme]. ESP32 mit Sensorik: 113 mA an 5 V. Wirkungsgrad MT3608: **η = 0,90 [Annahme]**. Das Datenblatt des Moduls nennt ausschließlich einen Bestwert von „bis zu 97 %" ohne Angabe von Eingangsspannung, Ausgangsspannung und Laststrom und ohne Wirkungsgradkurve. Dieser Wert ist für den Arbeitspunkt 3,7 → 5 V bei bis zu 1,18 A nicht übertragbar und wird deshalb **nicht** verwendet.

| Betriebsfall | Entnahme an +5 V | Leistung | Strom aus BT1 |
|---|---|---|---|
| Schlusslicht (D1 bei 20 % Duty) + ESP32 + Sensorik | 159 mA | 0,80 W | 0,24 A |
| Bremslicht 100 % + ESP32 + Sensorik | 338 mA | 1,69 W | 0,51 A |
| Bremslicht + beide Blinker 100 % (Warnblinker) | 786 mA | 3,93 W | **1,18 A** |

Der Worst-Case-Strom von 1,18 A fließt vollständig über SW1, da der Schalter im Akkupfad sitzt.

**Rechnerische Laufzeit im Dauerbetrieb mit Schlusslicht: rund 8 h.** Für η zwischen 0,85 und 0,95 verschiebt sich der Wert auf **7,9 bis 8,8 h**; die Aussage ist gegenüber der Wirkungsgradannahme also robust. Messtechnische Verifikation weiterhin erforderlich (NFR-PWR-02). Der Worst-Case-Eingangsstrom von 1,18 A ist der maßgebliche Lastfall für die Beurteilung des MT3608 (Kap. 12).

### 5.3 Hinweis zur Zustandsüberwachung
Keine Batteriespannungsmessung (OUT-01). Ladezustand nur über das USB-C-/TP4056-Modul. Konsequenz: keine Low-Battery-Warnung durch die Firmware.

### 5.4 Schaltplan Rev. 1.0 [neu, 09.08.2026]

Der Schaltplan liegt in einer Fassung vor, die dem realen Aufbau entspricht: `hardware/schaltplan_fahrrad_ruecklichtsystem.kicad_sch` (KiCad 7, bearbeitbar, Symbolbibliothek eingebettet) mit PDF-Export in A4 Querformat. Rev. 1.1 (09.08.2026) korrigierte die Position von SW1. **Gültiger Stand ist Rev. 1.3 vom 10.08.2026**; sie führt den nicht bestückten Antennendraht, die nicht bestückten Gate-Ableitwiderstände (Befund B-9) und den unbeschalteten EX_ANT-Anschluss des L86 ausdrücklich als dokumentierten Aufbaustand. Begleitdokumentation: `claude/Schaltplan_Dokumentation.md`.

Der frühere Schaltplan v2 vom 20.05.2026 ist damit **überholt**. Seine drei dokumentierten Fehler (RF an GPIO34 statt GPIO4, vertauschte Kanäle GPIO25/26, fehlende Gate-Pull-Downs) sowie die fehlenden Positionen SW1 und Entkopplungskondensatoren sind in Rev. 1.0 bereinigt.

**Umfang:** 28 Bauteile, 32 Netze, vier funktionale Bereiche (Stromversorgung, Mikrocontroller, Sensorik/Funkempfang, LED-Treiberstufe). Verbindungen zwischen den Bereichen laufen über Netzlabel und Versorgungssymbole; das Blatt enthält keine Leitungskreuzung.

**Verbindungsprüfung [gesichert].** Über die aus der Zeichnung exportierte Netzliste maschinell geprüft: alle 28 Bauteile vollständig verdrahtet, jedes Netz mit mindestens zwei Knoten. Die einzigen Einzelknoten sind die sechs bewusst offenen Pins des L86 (1PPS, FORCE_ON, AADET_N, RESET, EX_ANT, NC), die mit Nichtanschluss-Markierungen versehen sind und laut Datenblatt (Kap. 3.2) offen bleiben dürfen.

**Elektrische Plausibilitätsprüfung — Befunde.** Die Prüfung hat fünf Punkte ergeben; an der Schaltung wurde nichts geändert.

| Nr. | Befund | Bewertung |
|---|---|---|
| B-1 | Der ESP32 treibt GPIO17 mit 3,3 V; das L86-Datenblatt (Tab. 3) gibt für RXD1 **VIHmax = 3,1 V** an. Der absolute Grenzwert von 3,6 V wird nicht erreicht, der Betrieb erfolgt aber außerhalb der zugesicherten Bedingungen. Gegenrichtung unkritisch (TXD1 nominal 2,8 V gegen 2,48 V Schwelle). | **Anforderungsabweichung**, Entscheidung offen (Kap. 11.1) |
| B-2 | Am AMS1117-3.3 des DevKitC hängen jetzt alle vier Peripheriemodule. Worst Case rund 354 mA (BLE-Sendespitze + L86-Spitzenstrom 100 mA laut Datenblatt Tab. 12) bei 1,7 V Abfall → **0,60 W** im SOT-223-Gehäuse. | zu messen (Kap. 11.2) |
| B-3 | Die Last hängt an OUT+; im Ladebetrieb speist der TP4056 gleichzeitig Akku und System. Der Laststrom fließt durch die Strommessung des Ladereglers, die Abschalterkennung kann dadurch gestört werden. | bekannte Topologieeigenschaft, dokumentieren |
| B-4 | Das L86-Datenblatt (Kap. 3.3) empfiehlt 10 µF und 100 nF unmittelbar am VCC-Pin. Verbaut sind nur die beiden 1000-µF-Elkos an den Schienen; Elektrolytkondensatoren sind oberhalb einiger 10 kHz unwirksam. | dokumentierte Abweichung |
| B-5 | Kein Verpolungs- und kein Überstromschutz. Ein Kurzschluss im LED-Zweig würde nur durch die Strombegrenzung des MT3608 und den DW01 begrenzt. | bestätigter Aufbaustand (Kap. 12) |
| B-6 | SW1 liegt im Akkupfad und führt damit den Eingangsstrom des Wandlers: im Worst Case **1,18 A** bei 3,7–4,2 V statt 0,79 A auf der 5-V-Seite. Verbaut ist ein Wippschalter KCD1-2; das Typenschild nennt nur Wechselstromwerte (6 A / 250 V AC, 10 A / 125 V AC), eine **Gleichstromangabe fehlt**. Ein erhöhter Kontaktwiderstand wirkt hier zusätzlich direkt auf den Eingangsspannungsbereich des MT3608. | **zu prüfen** (Kap. 11.2) |
| **B-9** | **Die Gate-Ableitwiderstände R2/R4/R6 sind nicht bestückt.** Das Gate hängt nur über den 100-Ω-Serienwiderstand am GPIO. Während Reset und Hochlauf sind die GPIO Eingänge, das Gate ist in dieser Zeit hochohmig und der Zustand der drei Leuchten damit nicht definiert. | **Abweichung, dokumentiert (13.08.2026).** Im Betrieb kein auffälliges Verhalten beobachtet; das Init-Diagnose-Blinken überdeckt das Zeitfenster. Nachrüstung als Ausblick. Auf Entscheidung des Verfassers **nicht Gegenstand des Thesis-Texts**, aber im Schaltplan vermerkt |

**Als unkritisch geprüft:** GPIO-Belegung (acht verschiedene Pins, kein Strapping-Pin betroffen), I²C (Adressen 0x68/0x76 kollisionsfrei; zwei modulinterne Pull-Ups von je typisch 4,7 kΩ ergeben parallel 2,35 kΩ → 1,4 mA Low-Strom und rund 0,1 µs Anstiegszeit, beides weit innerhalb der Spezifikation), UART-Kreuzung (korrekt), MOSFET-Ansteuerung (**neu bewertet 11.08.2026, s. Befunde P-1 bis P-3 unten**), LED-Vorwiderstände (0,63 W je Kanal auf acht Bauteile verteilt, 31 % Auslastung bei 0,25-W-Typen).

**Thermische Stabilität der Vorwiderstandslösung [belegt 11.08.2026].** Mit I = (5 V − V_f)/12,5 Ω und dem für Leuchtdioden belegten Temperaturkoeffizienten dV_f/dT ≈ **−1 mV/K** [Hering u. a., 8. Aufl., S. 325] ergibt sich dI/dT = **0,08 mA/K**. Über 50 K Erwärmung steigt der Strom damit um 4 mA, also um **1,8 %**. Über dem Widerstand fallen mit 2,8 V mehr Spannung ab als über der LED mit 2,2 V, die Schaltung ist dadurch hinreichend steif. **Ein thermisches Weglaufen ist bei dieser Dimensionierung nicht zu erwarten**; das Risiko ist in Kap. 12 herabgestuft. Die bis v0.20 verwendeten −2 mV/K sind der Wert für Silizium-Kleinsignaldioden und waren für eine Leuchtdiode zu groß angesetzt; die Aussage wird durch die Korrektur stärker, nicht schwächer.

**Befunde aus der Datenblattprüfung des IRLZ44N [neu, 11.08.2026].**

| Nr. | Befund | Folge |
|---|---|---|
| P-1 | Die bis v0.20 verwendete Eingangskapazität von 3,3 nF steht nicht im Datenblatt. Angegeben sind C_iss = 1700 pF typ. bei V_DS = 25 V (Abb. 5: rund 2400 pF bei V_DS = 1 V). Zudem ist die RC-Abschätzung das falsche Modell; maßgeblich ist die Gate-Ladung. | Mit Q_gs + Q_gd = 33,6 nC und 18 bis 33 mA Gate-Strom folgen **1,0 bis 1,9 µs** statt der dokumentierten 0,33 µs. Die Schlussfolgerung „unter 1 % der Periodendauer von 200 µs" bleibt gültig, die Herleitung ist zu ersetzen. |
| P-2 | R_DS(on) ist bei V_GS = 3,3 V **nicht spezifiziert**. Der niedrigste angegebene Wert gilt für V_GS = 4,0 V mit 0,035 Ω max. | Die verwendeten 0,05 Ω sind eine Extrapolation und als **Annahme** zu kennzeichnen. Die Aussage bleibt robust: selbst mit 0,2 Ω sind es bei 224 mA nur 10 mW, bei R_thJA = 62 K/W also 0,6 K Übertemperatur. |
| P-3 | V_GS(th) = 1,0…2,0 V ist bei I_D = 250 µA definiert und markiert den Einsatz der Leitfähigkeit, nicht die volle Durchsteuerung. | Tragfähig ist das Argument über den Laststrom: die Plateauspannung liegt bei V_GS(th) + I_D/g_fs; mit g_fs = 21 S trägt der zweite Term bei 224 mA nur rund **11 mV** bei. Der Transistor arbeitet bei 3,3 V damit tief im ohmschen Bereich. |
| P-4 | Der Temperaturkoeffizient der LED-Durchlassspannung beträgt **−1 mV/K**, nicht −2 mV/K. | s. Absatz oben. |

---

## 6. Firmware

### 6.1 Entwicklungsumgebung
VS Code + **PlatformIO** + **Claude Code**. Plattform **pioarduino** → Arduino-ESP32-Core **3.3.11** (ESP-IDF 5.5.x). Board `esp32dev`, Partition `huge_app.csv` (No-OTA, CON-03). Host-Unit-Tests im `native`-Env (NFR-TST-03). Konfiguration ausschließlich über Übersetzungszeit-Konstanten in `include/config.h` (s. Kap. 12.2).

**Begründung pioarduino:** Die offizielle PlatformIO-Plattform `espressif32` liefert nur Arduino-Core 2.0.17 (kein `ledcAttach`).

**Build-Voraussetzung (macOS):** `liblzma` muss vorhanden sein (`brew install xz`).

### 6.2 Bibliotheken [versionsfest seit Commit `835c7b3`]

Alle Abhängigkeiten sind in `firmware/platformio.ini` auf exakte Versionen gepinnt. Begründung: Ohne Pinning löst PlatformIO bei jedem sauberen Build die jeweils neueste kompatible Version auf; ein Nachbau der Arbeit könnte damit gegen anderen Bibliothekscode laufen als der dokumentierte Validierungsstand (NFR-EXT-01, Reproduzierbarkeit).

| Bibliothek | Version | Verwendung |
|---|---|---|
| Adafruit MPU6050 | 2.2.9 | IMU-Treiber |
| Adafruit BMP280 | 3.0.0 | Barometer-Treiber |
| Adafruit Unified Sensor | 1.1.15 | gemeinsame Sensor-Abstraktion der Adafruit-Treiber |
| TinyGPSPlus | 1.1.0 | NMEA-Parser (L86) |
| rc-switch | 2.6.4 | 433-MHz-Dekodierung |
| NimBLE-Arduino | 2.5.0 | BLE-Transport |

### 6.3 Konventionen
PWM ausschließlich über `ledcAttach()`/`ledcWrite()`. Kooperativer nicht-blockierender Scheduler, kein `delay()` im Betrieb, statische Speicherverwaltung, Trennung Logik ↔ Hardware, ID-Referenzen in Kommentaren.

### 6.4 Repository (Monorepo)
`firmware/` (PlatformIO), `webapp/` (historisch), `docs/` (Bible-Kopie + Wissensdatenbank), `hardware/` (**ab 09.08.2026 mit Schaltplan Rev. 1.0**), `cad/`, `testdata/`. Logik hardwarefrei in `firmware/lib/logic`, Treiber in `firmware/lib/drivers`. Wissensdatenbank: `decision_log.md`, `current_context.md`, `roadmap.md`, `open_issues.md`, `lessons_learned.md`, `ble_brownout_fallstudie.md`.

### 6.4a Modulübersicht Firmware

| Ordner | Modul | Inhalt |
|---|---|---|
| `include/` | `pins.h` | GPIO-Zuordnung |
| `include/` | `config.h` | alle Konstanten (Motion-Filter-Parameter, Einbaulage, Schwellwerte) — einzige Konfigurationsquelle |
| `src/` | `main.cpp` | kooperativer Scheduler, Tasks, Bench-Harness (`BENCH_MODE`) |
| `lib/logic/` | `brake_curve` | Bremskennlinie FR-TL-06 (Proportionalteil, zustandslos) |
| `lib/logic/` | `tail_light_fsm` | Zustandsautomat Rücklicht/Bremslicht (R2), Hysterese und Mindesthaltezeit |
| `lib/logic/` | `lifecycle_fsm` | Lebenszyklus Init→Run, degraded (R1) |
| `lib/logic/` | `motion_filter` | **Normbetrags-Gate + Komplementärfilter → Längsverzögerung (Stufe 1)** |
| `lib/logic/` | `telemetry_window_agg` | Fensteraggregate des 100-Hz-Takts für Frame v3 |
| `lib/logic/` | `gnss_speed_ref` | GNSS-Referenzbeschleunigung (beobachtend, E5) |
| `lib/logic/` | `button_decoder` | RF-Signale → Tastenereignisse |
| `lib/logic/` | `blinker_fsm` | Zustandsautomat Blinker L/R/Warn (R3) |
| `lib/logic/` | `imu_health` | Plausibilität/Recovery/Fail-Safe |
| `lib/logic/` | `imu_mount_orientation` | **Rückabbildung der Einbaulage (Kap. 4.3), hardwarefrei, wird an der Treibergrenze aufgerufen** |
| `lib/logic/` | `telemetry_frame`, `telemetry_buffer` | Serialisierung und Ringpuffer |
| `lib/drivers/` | `led_output` | PWM-Ansteuerung LEDs |
| `lib/drivers/` | `imu_driver` | MPU6050 über I²C, DLPF/Sample-Rate fest konfiguriert |
| `lib/drivers/` | `rf_input` | 433-MHz-Empfänger |
| `lib/drivers/` | `bmp280_driver` | BMP280 über I²C |
| `lib/drivers/` | `gnss_driver` + `gnss_fix` | L86 über UART2, Fix-Status |
| `lib/drivers/` | `ble_telemetry` | BLE-Notify-Transport (NimBLE) |
| `test/` (native, Unity) | 15 Testdateien, u. a. `test_motion_filter`, `test_tail_light_fsm`, `test_imu_mount_orientation`, `test_frame_v3_golden`, `test_telemetry_window_agg` | **126/126 grün** (Commit `835c7b3`) |

### 6.5 Implementierungsstand [abgeschlossen, Commit `835c7b3`, 10.08.2026]

- **M0 Grundgerüst** ✅
- **M1 Rücklicht/Bremslicht R2** ✅ HW-validiert. Der am 08.08.2026 im Feld nachgewiesene Mangel M-01 (unwirksame Mindesthaltezeit) ist am **10.08.2026 behoben** und durch einen Regressionstest abgesichert (Kap. 9.5.4).
- **M2 Lebenszyklus R1** ✅ HW-validiert.
- **M3 Sensorik/Bremserkennung** ✅ **Stufe 1 umgesetzt und feldverifiziert (08.08.2026).** Einbaulage-Transformation nach Kap. 4.3 umgesetzt (10.08.2026). `imu_driver` mit fest gesetztem DLPF (44 Hz) und Sample-Rate (200 Hz); `motion_filter` mit Normbetrags-Gate, entkoppelter Bias-Kalibrierung und Nickwinkel-Verankerung. Der Validierungsstatus wird von „im Feld falsifiziert" (v0.16) auf **„im Feld verifiziert"** heraufgestuft (Kap. 9.5).
- **M4 Blinker + RF** ✅ Funktion HW-validiert (physische L/R-Zuordnung offen).
- **M5 Teil A Barometer** ✅ validiert.
- **M5 Teil B GNSS** ✅ validiert, Freilandfix erreicht.
- **M5 Teil C2 BLE-Telemetrie** ✅ am realen System validiert; **Frame-Schema v3 (113 Byte)** mit GNSS-Referenz, Filter-Innensicht und 100-Hz-Fensteraggregaten.
- **Härtung** ✅ am Board per Fehlerinjektion verifiziert.
- **M6 Konfiguration** — **abgegrenzt (10.08.2026).** FR-CFG-02 und FR-CFG-03 werden nicht umgesetzt; Begründung Kap. 12.2.
- **Host-Unit-Tests:** **126/126 grün** (125 bestehende + Regressionstest zu M-01).
- **Auslieferungsstand:** alle Debug-Ausgaben entfernt, `DEBUG_SERIAL = false`, keine `TODO`- oder `FIXME`-Marker im eigenen Quellcode. Binärgröße `esp32dev`: 674 487 B Flash (21,4 %), 106 912 B RAM (32,6 %).
- **Kreuztest über Toolchain-Grenzen** ✅ `testdata/frame_v3_golden.hex` (113 Byte, 41 unterscheidbare Werte): die Firmware erzeugt die Bytefolge, der Produktions-Decoder der iOS-App liest genau diese Bytes gegen die Wertetabelle — nicht gegen den eigenen Encoder.
- **Status: Die Firmware ist mit Commit `835c7b3` abgeschlossen und eingefroren.** Sie ist auf das Gerät geflasht und im Normalbetrieb geprüft. Weitere Änderungen sind nur noch bei einem funktionsverhindernden Fehler vorgesehen.

### 6.6 Zustandsmodell (vier parallele Regionen) [Block B/C/D]

| Region | Zustände | Treiber |
|---|---|---|
| R1 Lebenszyklus (STA) | `S_INIT`, `S_RUN`, `S_FAULT` (reserviert) | Power-On, Sensor-Init |
| R2 Rücklicht (TL) | `TL_INIT_BLINK`, `TL_SCHLUSSLICHT`, `TL_BREMSLICHT`, `TL_NOTBREMS_BLINKEN` (experimentell) | IMU-Verzögerung |
| R3 Blinker (BLK) | `BLK_AUS`, `BLK_LINKS`, `BLK_RECHTS`, `BLK_WARN` | 433-MHz-Fernbedienung |
| R4 Erfassung (SNS/TEL) | `SNS_ACQ` (ab RUN) + Telemetrie je nach BLE | zyklischer Timer |

**R2 Übergänge:** INIT → `TL_INIT_BLINK` (2 Hz, 0↔~50 %). RUN → `TL_SCHLUSSLICHT` (~20 %). `→ TL_BREMSLICHT` bei a ≥ 2,0; linear bis 100 % bei 5,0. `→ TL_SCHLUSSLICHT` bei a < 1,5 nach Ablauf der Mindesthaltezeit. `→ TL_NOTBREMS_BLINKEN` bei a ≥ 5,0 (nur experimentell); zurück bei a < 3,0.

> **Präzisierung 09.08.2026 (Mangel M-01).** Der Haltemechanismus greift erst, wenn der Eingang unter `BRAKE_OFF_MS2` = 1,5 fällt. Im Band zwischen 1,5 und 2,0 bleibt die FSM zwar im Zustand `TL_BREMSLICHT`, überschreibt aber den gehaltenen Duty-Wert mit dem Rückgabewert der Kennlinie — und der ist für jeden Wert ≤ 2,0 der Schlusslichtwert. Da jedes reale Bremssignal dieses Band durchläuft, hält die Mindesthaltezeit im Feld stets 20 %. Details und Messbeleg in Kap. 9.5.4.

**RF-Tastenerkennung (Sub-FSM vor R3, FR-RF-03/04):**
```
IDLE ──Code (≥2×)──▶ GEDRÜCKT ──(Lücke > ~150 ms)──▶ Loslassen
                        │                                └─ < 5 s: SHORT-Event
                        └──(gehalten ≥ 5 s)──▶ LONG-Event (Warnblinker)
```

**Zustandsdiagramm — Lebenszyklus + Rücklicht:**

```mermaid
stateDiagram-v2
    [*] --> INIT
    INIT --> RUN: krit. Sensoren ok ODER 5s Timeout
    state RUN {
        [*] --> SCHLUSSLICHT
        SCHLUSSLICHT --> BREMSLICHT: a >= 2.0
        BREMSLICHT --> SCHLUSSLICHT: a < 1.5 (Halten, dann 300ms)
        BREMSLICHT --> NOTBREMS: a >= 5.0 (experimentell)
        NOTBREMS --> BREMSLICHT: a < 3.0
    }
```

**Zustandsdiagramm — Blinker (R3):**

```mermaid
stateDiagram-v2
    [*] --> AUS
    AUS --> LINKS: kurz Taste1
    AUS --> RECHTS: kurz Taste2
    LINKS --> RECHTS: kurz Taste2 / Timer reset
    RECHTS --> LINKS: kurz Taste1 / Timer reset
    LINKS --> AUS: kurz Taste1 (Toggle)
    RECHTS --> AUS: kurz Taste2 (Toggle)
    LINKS --> AUS: 60s Timeout
    RECHTS --> AUS: 60s Timeout
    AUS --> WARN: Langdruck 5s
    LINKS --> WARN: Langdruck 5s
    RECHTS --> WARN: Langdruck 5s
    WARN --> AUS: kurzer Tastendruck
```

### 6.7 Fehlerbehandlung & Sicherheit [Block E]
Fail-safe auf Schlusslicht; Prioritätsordnung Schlusslicht > Bremslicht > Blinker > Telemetrie. IMU-Ausfall → sicheres Schlusslicht + Flag + Reinit; optionale Sensoren → Weiterbetrieb + Flag. I²C zeitbegrenzt, gestufte Recovery. Watchdog ~2 s. BLE-Isolation.

### 6.8 Ausführungsmodell [Block F]
Kooperativer, nicht-blockierender Scheduler: schnelle `loop()`, `millis()`-getaktete Tasks in fester Reihenfolge. Raster: IMU/Bremslicht 100 Hz, BMP 10 Hz, GNSS 1 Hz, Blinker 1,5 Hz, Telemetrie 10 Hz, Watchdog je Durchlauf. **Gemessenes Zeitverhalten im Fahrbetrieb s. Kap. 9.5.5.** Die dort gemessenen Spitzen fallen in den 1-Hz-Slot; ihre Ursachenzuordnung ist im Auslieferungsstand nicht mehr nachprüfbar (s. Kap. 9.5.5).

### 6.9 Konfiguration, Test & Erweiterbarkeit [Block G/H]

**Konfiguration:** Sämtliche Kalibrier-, Struktur- und Sicherheitswerte liegen als benannte `constexpr` in `include/config.h`; eine Änderung erfordert Neuübersetzung und Neuprogrammierung. Laufzeitkonfiguration über NVS und ein serielles Kalibrier-Interface waren als FR-CFG-02/03 spezifiziert und sind am 10.08.2026 abgegrenzt worden (Kap. 12.2). Der praktische Nachteil ist gering, weil im Rahmen dieser Arbeit ausschließlich am Entwicklungsrechner parametriert wurde; die Anforderung bleibt als Ausblick bestehen.

**Testbarkeit:** Trennung Logik ↔ Hardware (NFR-TST-01), Host-Unit-Tests im `native`-Env (126/126), On-Target-Validierung und Golden-Vektor-Kreuztest über die Toolchain-Grenze hinweg.

**Erweiterbarkeit:** modulare Schnittstellen, versioniertes Telemetrie-Frame (Schema v3), versionsfest gepinnte Bibliotheken.

---

## 7. App (iOS)

### 7.1 Zielarchitektur
Native iOS-App. Rolle (FR-SYS-01) unverändert: Rechen- und Datensenke — empfängt das versionierte Telemetrie-Frame (10 Hz, FR-TEL-06) per BLE, berechnet Statistik/Sensorfusion, speichert die Fahrt (CON-01), visualisiert die MVP-Kennzahlen.

### 7.2 Kommunikationsmodell
Unidirektional ESP32 → App (FR-SYS-04): ein GATT-Service mit einer einzigen NOTIFY-Characteristic. **Aktueller Vertrag: Frame-Schema v3, 113 Byte**, Offsets 0–80 byte-identisch zu v2. Verbindliche Fassung: `claude/BLE_Frame_v3_Schnittstelle.md`. Am realen Gerät verifiziert (Advertising, MTU 185, Notify-Subscribe).

### 7.3 Technik
Swift/SwiftUI, SF Symbols, Swift Charts, Core Bluetooth, SwiftData.

### 7.4 Entwicklung
iOS-App in Xcode (26.3+) mit eingebautem Claude-Assistenten; Firmware in VS Code + Claude Code. Verbunden über den gemeinsamen BLE-Frame-Vertrag. App-SSOT ist die separate **App Bible** (`claude/app_bible.md`, aktuell v0.22).

### 7.5 Signierung & Verteilung (Eigennutzung)
Gratis-Weg über ein Personal Team. Installation per USB aus Xcode; Profil läuft nach 7 Tagen ab. Kein Apple Developer Program, kein TestFlight erforderlich.

### 7.6 Stand
**Schema-v3-Migration (AP0–AP8) abgeschlossen, 89 Tests grün, committet.** Umgesetzt: Decoder auf 113 Byte mit Mindestversions-/Längenregel, reiner Decoder mit Ergebnis-Enum, gemeinsamer `TelemetryFrameEncoder` als einzige Byte-Quelle für Mock und Round-Trip-Test, additive Persistenz-Erweiterung um die 13 v3-Felder, umschaltbarer 10-Hz-Validierungsmodus mit Batch-Persistenz, CSV-Export mit 35 Spalten und eingefrorenem Golden-Header, read-only Diagnoseansicht. **Golden-Vektor-Kreuztest bestanden.** Am realen iPhone verifiziert: `truncatedV3FrameCount = 0`.

**Offen (App):** Cockpit-Editor (AR-LIVE-08), finale SF-Symbol-Wahl, optionale Höhen-Referenzdruck-Kalibrierung — alles Future Work.

**Format-Referenz für externe Auswertungen:** `claude/CSV_Format_v3_Validierungsexport.md` — 35 Spalten, Semikolon, deutsches Dezimalkomma, CRLF, UTF-8 mit BOM.

---

## 8. Konstruktion

Zu berücksichtigen: additive Fertigung, Toleranzen, Montage/Wartung, Kabelführung, Bauraum, Wärmeabfuhr (Werkstoffgrenzen PETG), Schraubverbindungen, Vibrationsfestigkeit, Feuchtigkeit/Outdoor. Bauraum-Referenz Akku: LP103454 (10,3 × 34 × 54 mm).

**Werkstoff [gesichert, 10.08.2026 · Begründung präzisiert 11.08.2026]:** Das Gehäuse wird im FDM-Verfahren aus **PETG** gefertigt, nicht aus PLA. Frühere Fassungen dieser Bible nannten durchgängig PLA; das war eine Fehlangabe. **Tragende Begründung ist die thermische Belastung** nach KON-06: Die Vorwiderstandsnetze RN1–RN3 und die Transistoren Q1–Q3 sind die einzige nennenswerte Verlustleistungsquelle im Gerät, und PETG besitzt eine höhere Glasübergangstemperatur als PLA. **Ergänzung 13.08.2026:** Der zweite Teil derselben Begründung ist die Stromreduktion der Leuchten. Das Datenblatt des typgleichen Vergleichsbauteils gibt bei Dauerstrom eine Sperrschichttemperatur von typisch 115 °C gegen einen Grenzwert von 120 °C an. Bei Nennstrom bliebe in einem geschlossenen Kunststoffgehäuse also praktisch keine Reserve. Erst der Betrieb bei rund einem Viertel des Dauerstroms macht die gewählte Bauweise tragfähig. Die höhere Zähigkeit und die Witterungsbeständigkeit sind willkommene Nebeneffekte, aber **keine** Begründung, weil ihnen keine Anforderung gegenübersteht — für das System sind keine Umgebungsanforderungen festgelegt (Kap. 2.13, Systemgrenze Trockenbetrieb). Die Auslegung des LED-Stroms auf rund 224 mA statt des Nennstroms bleibt davon unberührt und ist in Kap. 5.4 begründet.

**Verbindungstechnik [gesichert, 10.08.2026]:** Gehäuse und Lochrasterplatine werden verschraubt. Eingesetzt werden **Einschmelzgewinde M3 × 5 × 5** in den gedruckten Bauteilen sowie Schrauben **M3 × 6** und **M3 × 8**.

**Konstruktionsstand:** vom Verfasser bearbeitet (Bauraumanalyse, Gehäusekonzept, Druck erfolgt). Eine detaillierte Aufnahme des Konstruktionsstands in diese Bible steht noch aus.

**Neue Randbedingung aus dem L86-Datenblatt (Kap. 4.1.2) [09.08.2026]:** Da die interne Patch-Antenne genutzt wird, fordert der Hersteller freie Sicht nach oben, ein nichtmetallisches Gehäuse im Antennenbereich, mindestens 10 mm Abstand zu Bauteilen über 6 mm Höhe und mindestens 10 mm Abstand zu anderen Antennen. Die BLE-Antenne des ESP32 sitzt auf derselben Lochrasterplatine — der Abstand ist bei der Gehäusekonstruktion und einer eventuellen Neuanordnung zu beachten.

**Weitere Randbedingung [09.08.2026]:** Die Lochrasterplatine ist um 180° gedreht verbaut (Kap. 4.3). Damit haben sich Position der IMU relativ zur Nickachse, Lage der 433-MHz-Antenne und Lage des LED-Leistungspfads relativ zur IMU geändert. Die Ruhe-Rauschwerte vom 07.08.2026 sind deshalb nicht unbesehen auf den neuen Aufbau übertragbar.

---

## 9. Validierung

| Funktion | Status |
|---|---|
| ESP32-Grundfunktion | ✅ validiert |
| SRX882S RF-Empfang · Fernbedienungscodes | ✅ validiert |
| **Reichweite und Erkennungsrate der Funkstrecke** | ✅ **erstmals gemessen (12.08.2026, Kap. 9.6).** In Einbaulage 19/20 und 18/20 erkannte Tastendrücke, Reichweite bis 3 m gesichert. Ohne Drahtantenne, Körper im Signalweg |
| Fernbedienung Kurz-/Langdruck- & Wiederhol-Timing | ⚠️ **abgegrenzt (Kap. 12.2)** — im Feldbetrieb ohne Fehlfunktion bestätigt, systematische Messung des Wiederholintervalls nicht Teil des Arbeitsumfangs |
| BMP280 (I²C 0x76), FORCED-Mode | ✅ validiert (Befund s. 9.1); Plausibilitätsprüfung/Recovery abgegrenzt (Kap. 12.2) |
| MPU6050 (I²C 0x68) | ✅ validiert |
| IMU-Rohdatenerfassung (`imu_driver`, DLPF 44 Hz / 200 Hz Sensorrate) | ✅ HW-validiert, Registerauslesung bestätigt |
| **Bremserkennung (`motion_filter`, Stufe 1)** | ✅ **im Feld verifiziert (08.08.2026):** alle neun Referenz-Bremsvorgänge erkannt; r = +0,85 gegen die GNSS-Referenz bei festem Versatz; keine Fehlauslösung beim Beschleunigen; Ruhesockel verschwunden (Kap. 9.5) |
| Bremslicht-Kennlinie (FR-TL-06), Proportionalteil | ✅ **bench- und feldvalidiert** (Feld: 194/194 Zeilen auf ±1 Prozentpunkt) |
| **Mindesthaltezeit 300 ms (FR-TL-06)** | ✅ **behoben 10.08.2026.** Im Fahrbetrieb war sie in keinem der 14 Fälle wirksam (Mangel M-01); Ursache korrigiert, Regressionstest durch das Hystereseband ergänzt, am Gerät bestätigt (Kap. 9.5.4). Feldmessung des korrigierten Verhaltens nicht durchgeführt (Kap. 12.2) |
| Bremslicht-Reaktionszeit ≤ 50 ms (NFR-RT-01) | ✅ Serial-Bench validiert (≤ 10 ms) |
| **Loop-Zykluszeit < 10 ms (NFR-RT-04)** | ✅ **im Fahrbetrieb erfüllt:** Worst Case 6,7 ms, 0,00 % der Fenster über 10 ms (Kap. 9.5.5). Ursachenzuordnung der 1-Hz-Spitze zurückgenommen; im Auslieferungsstand entfällt die UART-Last |
| Bias-Kalibrierung / Nickwinkel-Verankerung | ✅ im Feld wirksam (`bias_calibrated` ab dem ersten Frame) |
| Feldkalibrierung der Bremsschwellen | ⚠️ **abgegrenzt** (Umfangsschnitt 07.08.2026); Verhalten dokumentiert statt iteriert |
| GPS L86 – NMEA/UART · GPS-Fix (Freiland) | ✅ validiert |
| GNSS-Integrität unter Abschattung | ⚠️ **ungeprüft.** Der Abschattungsversuch fand im bewegten Zustand statt und ist ergebnislos; der frühere kritische Befund ist zurückgezogen (Kap. 9.4). Eine Integritätsprüfung liegt damit nicht vor |
| PlatformIO-Umgebung, Host-Unit-Tests | ✅ **126/126 grün** (Commit `835c7b3`) |
| Golden-Vektor-Kreuztest Firmware ↔ App | ✅ bestanden |
| R1-Lebenszyklus · R2-Zustandslogik | ✅ HW-validiert |
| Blinker-Funktion | ✅ HW-validiert; physische L/R-Zuordnung ❌ offen |
| I²C-Bus-Recovery · Watchdog-Reset · Fail-Safe | ✅ per Fehlerinjektion verifiziert |
| BLE-Transport · iOS-App gegen reale Verbindung | ✅ validiert |
| **Schaltplan Rev. 1.3, Verbindungsprüfung** | ✅ **maschinell über die Netzliste geprüft (Kap. 5.4)**; 28 Bauteile, 32 Netze, keine unerwarteten Einzelknoten |
| Energiebilanz/Laufzeit unter realen Lastfällen | ❌ offen — Messung (NFR-PWR-02) |
| Brown-Out unter realer LED-Lastspitze | ❌ offen |
| Verlustleistung AMS1117 unter Spitzenlast (B-2) | ❌ offen — Messung |
| Ladeinfrastruktur unter Last (B-3) | ❌ offen — Messung |
| Achsentransformation nach dem Umbau (Kap. 4.3) | ✅ **umgesetzt und geflasht 10.08.2026.** Host-Test vorhanden, Determinante +1 geprüft, im Normalbetrieb am Gerät bestätigt. Systematische Nachmessung der Referenzwerte abgegrenzt (Kap. 12.2) |
| Lichtstärke (cd) nach § 67 | ❌ offen — photometrische Messung |
| Gehäuse | ❌ nicht begonnen |

### 9.1 Validierungsbefunde M5A

**Druck:** Sensor 1002,5–1002,6 hPa vs. Referenz 1000,8 hPa (+1,6 hPa) → innerhalb Absoluttoleranz zzgl. QFE-Differenz; relative Genauigkeit ±0,12 hPa ausreichend.

**Temperatur [Annahme/vorläufig]:** ~29,0 °C bei 25,8 °C Raumreferenz, nicht thermisch eingeschwungen. Re-Test ausstehend. Gesichert: deutlich reduziertes Rauschen (±0,03 hPa / ±0,05 °C @ 1 Hz).

### 9.2 Akkubetrieb-Freeze (aufgeklärt)

Bremslicht fror ein, wenn das USB-Kabel im ESP32 steckte, aber am Host-Ende getrennt war (floatende VBUS-Leitung → unruhige 3,3-V-Schiene → I²C-Aussetzer). Im echten Akkubetrieb nicht reproduzierbar. **Lesson Learned:** „Debug-Setup ≠ Feldbedingung."
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

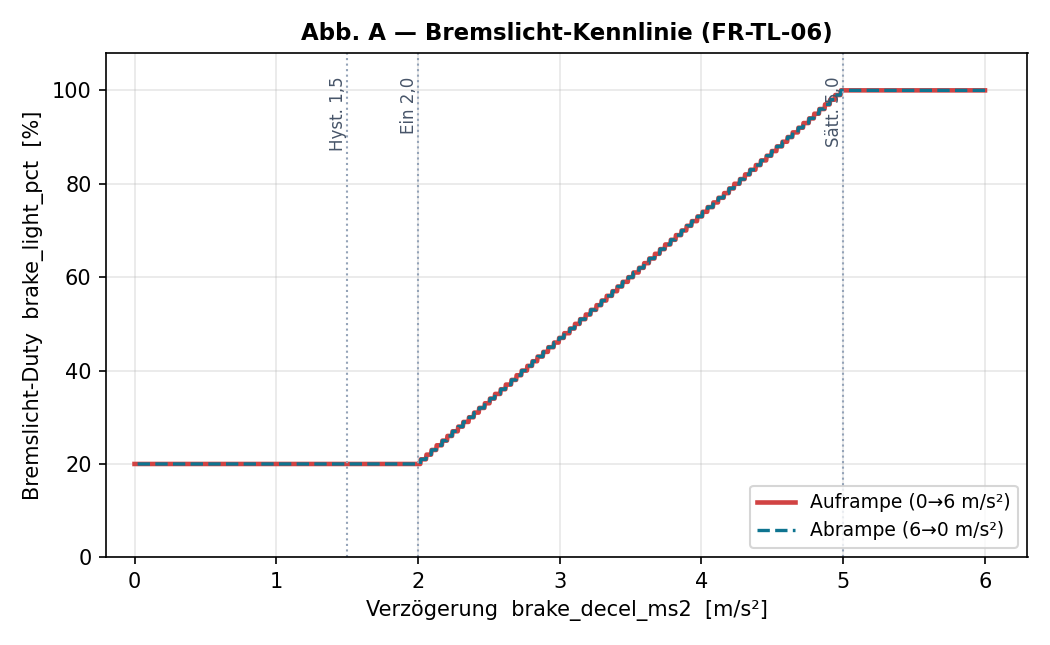
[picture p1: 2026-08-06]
docs/Validierung/abb_A_kennlinie.png

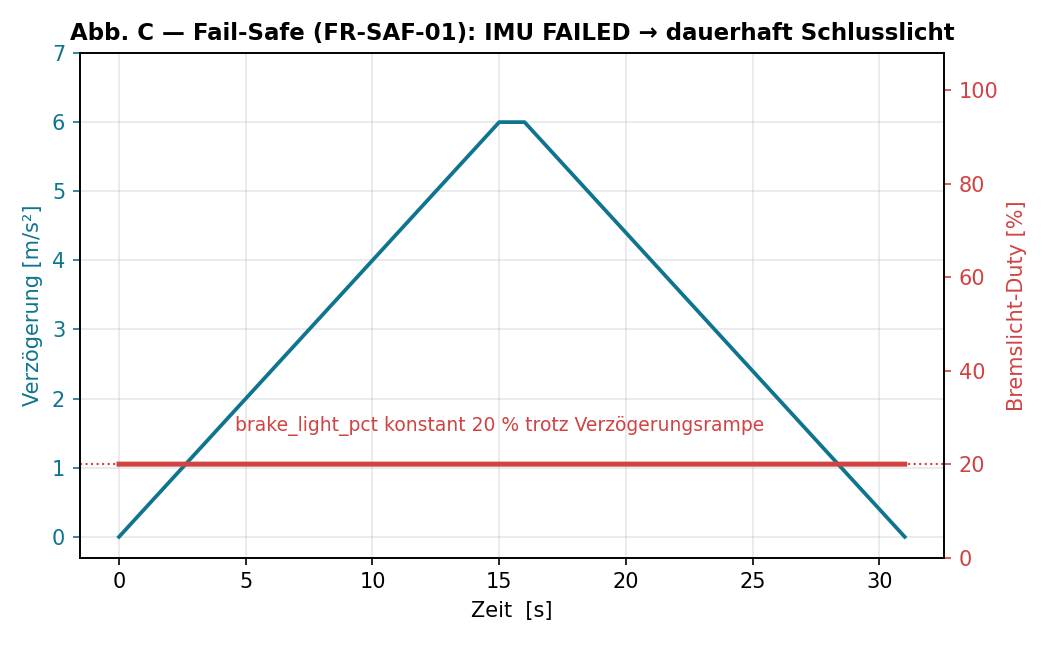
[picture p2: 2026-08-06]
docs/Validierung/abb_C_failsafe.png

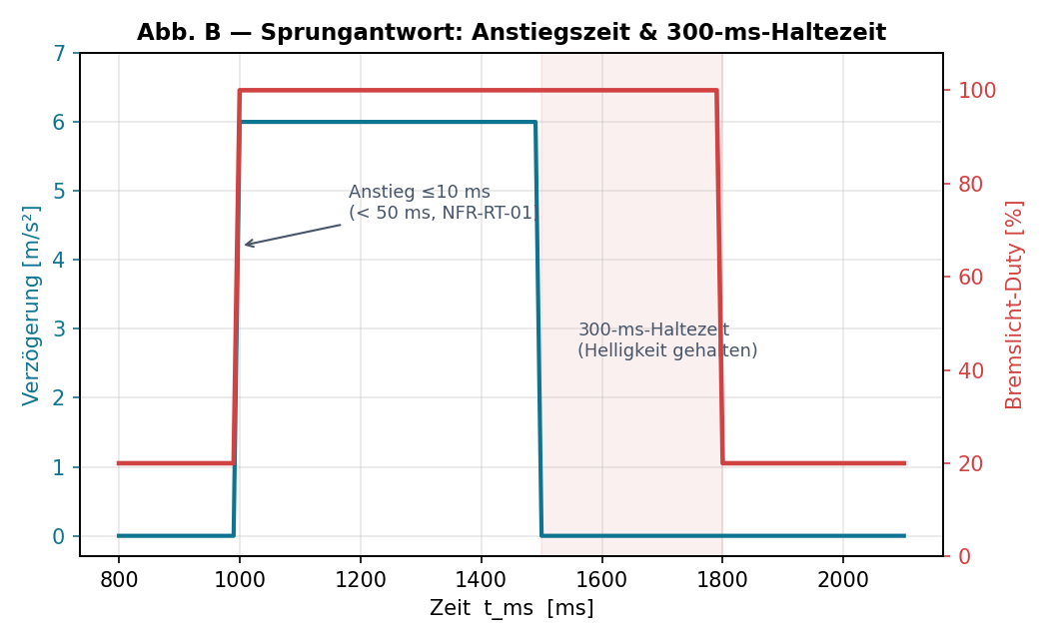
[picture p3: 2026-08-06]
docs/Validierung/abb_B_sprung.png

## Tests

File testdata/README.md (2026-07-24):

# testdata/

Aufgezeichnete/synthetische Sensordaten für reproduzierbare Host-Logik-Tests
(NFR-TST-02) — z. B. Verzögerungsprofile echter Bremsungen zur Prüfung der
Bremskennlinie (FR-TL-06) und der Notbrems-Erkennung (FR-TL-07). Format (CSV o. ä.)
beim ersten Datensatz festlegen und hier dokumentieren.

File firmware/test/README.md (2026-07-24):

# firmware/test — Host-Unit-Tests (NFR-TST-03)

Tests der reinen Logik, ausgeführt auf dem PC (kein ESP32 nötig):

```bash
pio test -e native
```

Konvention: pro Logik-Modul eine Testdatei unter `test_logic/`. Aufgezeichnete
Sensordaten für datengetriebene Tests (NFR-TST-02) liegen in `../../testdata/`.
On-Target-Tests (Hardware) laufen separat gemäß Validierungsplan (Bible Kap. 9).

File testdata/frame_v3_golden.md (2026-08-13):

# Golden-Referenz-Frame v3 — Schnittstellen-Kreuztest

**Zweck:** `frame_v3_golden.hex` enthält die 113 Byte (226 Hex-Zeichen, eine
Zeile) eines mit fest definierten, gut unterscheidbaren Werten serialisierten
Schema-v3-Telemetrie-Frames. Firmware (`firmware/test/test_frame_v3_golden/`)
und App testen damit **dieselbe eingefrorene Bytefolge**, nicht nur die
Symmetrie ihres eigenen Encoders gegen ihren eigenen Decoder — ein
gemeinsamer Denkfehler (falscher Offset, falsche Skalierung) auf beiden
Seiten bliebe sonst unsichtbar.

**Quelle:** `firmware/lib/logic/telemetry_frame.cpp::telemetryFrameSerialize()`,
Werte definiert in `firmware/test/test_frame_v3_golden/test_frame_v3_golden.cpp::buildGoldenFrame()`.
Layout gemäß `docs/BLE_Frame_v3_Schnittstelle.md` Kap. 3.

**Herkunft der Bytefolge:** erzeugt mit Commit `1178017` vom 07.08.2026
(letzte Änderung an `frame_v3_golden.hex` sowie an
`telemetry_frame.cpp`/`.h`, im Repo per `git log` verifiziert); seither
unverändert. Ablieferungsstand der Firmware ist Commit `835c7b3` vom
10.08.2026 — die Bytefolge selbst ist davon nicht betroffen, da Schema v3
und Serialisierung seit `1178017` unangetastet blieben. Umfang: 44 Felder
/ 113 Byte / 39 unterscheidbare Werte (s. Werte-Tabelle unten).

**Diese Datei ist bewusst eingefroren, nicht automatisch nachzuziehen.**
Ändert sich das Frame-Layout oder eine Skalierung absichtlich, müssen
`frame_v3_golden.hex` und diese Tabelle bewusst neu erzeugt (Firmware-Test
einmal mit gelöschter `.hex`-Datei laufen lassen) und im Diff geprüft werden.

## Werte-Tabelle

Float-Werte sind IEEE-754-`float32` — der App-seitige Vergleich sollte mit
einer kleinen Toleranz (z. B. `1e-4`) erfolgen, nicht auf exakte Gleichheit
(s. Spalte „Serialisiert", die den tatsächlich aus der Bytefolge dekodierten
`float32`-Wert zeigt).

| Offset | Bytes | Typ | Feld | Gesetzter Wert | Serialisiert (float32) |
|---|---|---|---|---|---|
| 0 | 2 | uint16 | `version` | 3 | — |
| 2 | 4 | uint32 | `timestamp_ms` | 305419896 (0x12345678) | — |
| 6 | 4 | float | `accel_x_ms2` | 1.1 | 1.100000023841858 |
| 10 | 4 | float | `accel_y_ms2` | 2.2 | 2.200000047683716 |
| 14 | 4 | float | `accel_z_ms2` | 3.3 | 3.299999952316284 |
| 18 | 4 | float | `gyro_x_rads` | 4.4 | 4.400000095367432 |
| 22 | 4 | float | `gyro_y_rads` | 5.5 | 5.5 |
| 26 | 4 | float | `gyro_z_rads` | 6.6 | 6.599999904632568 |
| 30 | 4 | float | `brake_decel_ms2` | 7.7 | 7.699999809265137 |
| 34 | 4 | float | `pressure_pa` | 101325.5 | 101325.5 |
| 38 | 4 | float | `temperature_c` | 23.4 | 23.399999618530273 |
| 42 | 4 | float | `lat` | 51.2277 (double, Downcast) | 51.227699279785156 |
| 46 | 4 | float | `lon` | 6.7735 (double, Downcast) | 6.773499965667725 |
| 50 | 4 | float | `speed_kmph` | 25.5 | 25.5 |
| 54 | 4 | float | `course_deg` | 123.4 | 123.4000015258789 |
| 58 | 4 | float | `altitude_m` | 45.6 | 45.599998474121094 |
| 62 | 1 | uint8 | `sats` | 11 | — |
| 63 | 4 | float | `hdop` | 1.23 | 1.2300000190734863 |
| 67 | 2 | uint16 | `utc_year` | 2026 | — |
| 69 | 1 | uint8 | `utc_month` | 8 | — |
| 70 | 1 | uint8 | `utc_day` | 7 | — |
| 71 | 1 | uint8 | `utc_hour` | 15 | — |
| 72 | 1 | uint8 | `utc_minute` | 42 | — |
| 73 | 1 | uint8 | `utc_second` | 33 | — |
| 74 | 1 | uint8 | `system_state` | 1 (Run) | — |
| 75 | 1 | uint8 | `init_degraded` | 1 (true) | — |
| 76 | 1 | uint8 | `imu_health_state` | 2 (FAILED) | — |
| 77 | 1 | uint8 | `baro_valid` | 1 (true) | — |
| 78 | 1 | uint8 | `gnss_fix_status` | 2 (FIX_OK) | — |
| 79 | 1 | uint8 | `watchdog_recovered` | 1 (true) | — |
| 80 | 1 | uint8 | `brake_light_pct` | 88 | — |
| 81 | 4 | float | `gnss_accel_ms2` | 8.8 | 8.800000190734863 |
| 85 | 4 | float | `pitch_rad` | 0.1234 | 0.1234000027179718 |
| 89 | 4 | float | `gyro_bias_rads` | 0.005678 | 0.0056779999285936356 |
| 93 | 4 | float | `norm_delta_min` | -1.11 | -1.1100000143051147 |
| 97 | 4 | float | `norm_delta_max` | 9.99 | 9.989999771118164 |
| 101 | 4 | float | `jerk_max` | 1.357 | 1.3569999933242798 |
| 105 | 1 | uint8 | `regime_static_n` | 3 | — |
| 106 | 1 | uint8 | `regime_dynamic_n` | 6 | — |
| 107 | 1 | uint8 | `regime_shock_n` | 2 | — |
| 108 | 1 | uint8 | `bias_calibrated` | 1 (true) | — |
| 109 | 1 | uint8 | `gnss_accel_valid` | 1 (true) | — |
| 110 | 1 | uint8 | `dt_max_ms` | 13 | — |
| 111 | 2 | uint16 | `loop_max_us` | 4567 | — |

**Gesamtlänge: 113 Byte.**

## Verwendung app-seitig

`frame_v3_golden.hex` als `Data` einlesen, durch den v3-Decoder schicken und
jedes Feld gegen die Spalte „Gesetzter Wert" prüfen (Floats mit Toleranz,
s. o.). Ein Fehlschlag bedeutet: Offset, Typ, Skalierung oder Byte-Reihenfolge
weicht zwischen Firmware-Encoder und App-Decoder ab — genau der
Fehlerklasse, die die getrennten Symmetrie-Tests beider Seiten nicht
aufdecken können.

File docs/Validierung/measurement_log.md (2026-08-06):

# Messprotokoll — Validierung der Bremslicht-Logik (Serial-Bench)

**Bachelorarbeit Krahl · Smart Bike Rear Light**

| Feld | Wert |
|---|---|
| Datum / Uhrzeit | 05.08.2026, 23:10 CEST |
| Prüfer | Luca Krahl |
| Prüfling (Board) | Espressif ESP32-DevKitC-32E (WROOM-32E) |
| Firmware-Stand (Git-Hash) | `d8a4e75` (Bench-Env `esp32dev_bench`, `-D BENCH_MODE`) |
| Schnittstelle / Port | UART0, 115200 Baud, `/dev/cu.usbserial-110` |
| Abtastrate Log | 100 Hz (10 ms), lückenlos (3101 / 351 / 3101 Datenzeilen) |
| Bench-Modus | `BENCH_MODE`, synthetische Verzögerungs-Einspeisung (NFR-TST-02) |
| FR-TL-07 (Notbrems-Blinken) | deaktiviert (Default) |
| Auswertung | Python/pandas, unabhängig aus den Rohdaten reproduziert |

## 1. Ziel
Nachweis der Bremslicht-Regellogik nach **FR-TL-06** (Bremskennlinie), ihres **zeitlichen/zustandsbehafteten** Verhaltens (300-ms-Haltezeit, Hysterese, Anstiegszeit) sowie des **Fail-Safe-Verhaltens** nach **FR-SAF-01**. Gemessen wird die **kommandierte** LED-Duty (`brake_light_pct`, Ausgang der Bremslogik) als Funktion des Verzögerungs-Eingangs (`brake_decel_ms2`).

## 2. Aufbau & Methodik
Kontrollierter **Bench-Test** (Werkbank, kein Fahrbetrieb). Über den firmwareseitigen Test-Daten-Hook (NFR-TST-02) wird ein **definiertes Verzögerungsprofil** in denselben Signalpfad gespeist, der im Normalbetrieb die Bremslicht-Duty erzeugt (`motion_filter` → `brake_curve` → `tail_light_fsm`); der geloggte Ausgang spiegelt damit das **reale, integrierte FSM-Verhalten** auf dem Ziel-MCU inkl. Halten/Hysterese/Fail-Safe. Aufzeichnung bei 100 Hz über die serielle Schnittstelle.

**Begründung:** Die synthetische Einspeisung ist **reproduzierbar** und durchfährt die Schwellen (2,0 / 5,0 / 1,5 m/s²) kontrolliert; die 100 Hz lösen die schnellen Effekte (Anstieg < 50 ms, 300-ms-Halten) auf, die im 1-Hz-App-Export untergehen.

**Abgrenzung:** Gemessen wird die *kommandierte* Duty (Steuerlogik-Nachweis). Die *physikalische* LED-Helligkeit als Funktion der Duty ist eine separate Hardware-Eigenschaft (optional per Oszilloskop am MOSFET-Gate GPIO26). Der GPIO26-Kanal wurde während der Bench parallel real angesteuert (visuell am Board nachvollziehbar). Ergänzend belegt der **Feldtest** (30-Zone, App-Export @ 1 Hz + Beobachtung) das reale Ansprechen.

## 3. Randbedingungen (Sollwerte aus SRS / `config.h`)
| Parameter | Sollwert (FR-TL-06) |
|---|---|
| Schlusslicht-Grundhelligkeit | ~20 % PWM |
| Ansprechschwelle Bremslicht | 2,0 m/s² |
| Sättigung (100 %) | 5,0 m/s² |
| Ausschalt-Hysterese (Rückfall) | < 1,5 m/s² |
| Mindesthaltezeit | 300 ms |
| Reaktionszeit (Ereignis → LED) | ≤ 50 ms (NFR-RT-01) |

## 4. Experimente

### 4.1 Experiment A — Kennlinie (Rampe) · `bench_A_kennlinie_rampe.csv`
Eingang: 0 → 6,0 m/s² (15 s), 1 s halten, 6,0 → 0 (15 s). Auswertung `brake_light_pct` über `brake_decel_ms2`.

| Kenngröße | Soll | **Ist (gemessen)** | Bewertung |
|---|---|---|---|
| Grundhelligkeit (decel < 2,0) | ~20 % | **20 %** (konstant) | ✔ |
| Ansprechschwelle (Zustand Schluss→Brems) | 2,0 m/s² | **2,00 m/s²** (decel = 2,004) | ✔ |
| Sättigung 100 % | 5,0 m/s² | **≈ 5,0 m/s²** (decel = 4,98) | ✔ |
| Verlauf 2,0–5,0 m/s² | linear | **linear**, `pct = 26,66·decel − 33,32`, **R² = 0,99984** (theoret. 26,67) | ✔ |
| Hysterese-Rückfall (Zustand Brems→Schluss) | < 1,5 m/s² | **decel = 1,38 m/s²** (Zustandswechsel bei t = 27 560 ms) | ✔ (s. Hinweis) |

*Hinweis Hysterese:* Die Duty-Kennlinie ist einwertig (Auf- und Abrampe decken sich, s. Abb. A) — die **Hysterese wirkt auf Zustandsebene** (`fsm_state`), nicht auf dem geklammerten %-Wert. Auf der langsamen Abrampe unterschreitet die Verzögerung 1,5 m/s² bei t = 27 260 ms; der Zustandswechsel erfolgt **exakt 300 ms später** (t = 27 560 ms, dann decel = 1,38 m/s²). Der gemessene „Rückfall bei 1,38" ist also die korrekte Überlagerung aus **1,5-m/s²-Schwelle + 300-ms-Mindesthaltezeit** — kein Fehler, sondern spezifikationskonform.

**Abbildung A:** `abb_A_kennlinie.png` — Bremslicht-Kennlinie (Duty % über Verzögerung), Auf-/Abrampe, Marken Ein 2,0 / Sätt. 5,0 / Hyst. 1,5.

### 4.2 Experiment B — Zeitverhalten (Sprung) · `bench_B_zeitverhalten_sprung.csv`
Eingang: 1 s bei 0 → Sprung 6,0 m/s² für 0,5 s → 0 → 2 s Nachlauf.

| Kenngröße | Soll | **Ist (gemessen)** | Bewertung |
|---|---|---|---|
| Anstiegszeit (Ereignis → 100 %) | ≤ 50 ms | **≤ 10 ms** (20 %→100 % innerhalb eines Abtastschritts) | ✔ (komfortabel) |
| Haltezeit nach Bremsende | 300 ms | **300 ms** (Duty bleibt 100 % von t = 1500 bis 1800 ms) | ✔ (exakt) |
| Rückfall auf Schlusslicht danach | ja | **ja** (→ 20 % ab t = 1800 ms) | ✔ |

**Abbildung B:** `abb_B_sprung.png` — Sprungantwort: schneller Anstieg + gehaltene Helligkeit über 300 ms (kein Sofortabfall, FR-TL-06).

### 4.3 Experiment C — Fail-Safe (IMU FAILED) · `bench_C_failsafe.csv`
Bedingung: `imu_health = FAILED`, dabei Rampe 0 → 6,0 → 0.

| Kenngröße | Soll | **Ist (gemessen)** | Bewertung |
|---|---|---|---|
| Bremslicht-Duty trotz hoher Verzögerung | ~20 % (Schlusslicht) | **20 % konstant** über den gesamten 0→6→0-Rampenlauf | ✔ |
| Zustand | Schlusslicht | **`fsm_state` durchgängig = Schlusslicht** | ✔ |
| Fehler-Flag | FAILED | **`imu_health` durchgängig = 2 (FAILED)** | ✔ |

**Abbildung C:** `abb_C_failsafe.png` — Fail-Safe: Bremslicht bleibt Schlusslicht (20 %) trotz Verzögerungsrampe.

## 5. Ergebnis (Soll/Ist-Zusammenfassung)
**Alle geprüften Kenngrößen liegen innerhalb der Spezifikation.** Die Bremskennlinie (FR-TL-06) ist bestätigt: 20 % Grundhelligkeit, Ansprechen bei 2,0 m/s², linearer Anstieg (R² = 0,9998) bis 100 % Sättigung bei 5,0 m/s². Das zustandsbehaftete Verhalten greift exakt wie spezifiziert: **Anstieg ≤ 10 ms** (NFR-RT-01 ≤ 50 ms deutlich erfüllt), **300-ms-Mindesthaltezeit** (exakt), **Hysterese-Rückfall bei 1,5 m/s²** (auf Zustandsebene, kombiniert mit der Haltezeit). Der **Fail-Safe** (FR-SAF-01/FR-STA-04) hält bei IMU-Ausfall durchgängig das Schlusslicht.

## 6. Diskussion & Einordnung
Die Messung bestätigt sowohl die statische Kennlinie als auch — und das ist der Mehrwert des 100-Hz-Bench gegenüber dem 1-Hz-App-Export — die **schnellen, zustandsbehafteten Effekte**. Die einwertige Duty-Kennlinie und die auf Zustandsebene wirkende Hysterese sind physikalisch konsistent: das Bremslicht folgt der Kennlinie, hält aber die Helligkeit 300 ms (kein Flackern bei kurzen Bremsstößen). Grenzen der Methode: (a) gemessen wird die *kommandierte* Duty, nicht die photometrische Lichtstärke (separate Hardware-Charakterisierung, optional per Oszilloskop); (b) die Verzögerung wird *synthetisch* eingespeist — der **Feldtest** ergänzt dies um das reale Ansprechen unter Fahrbedingungen. Beide zusammen (präzise Bench-Kennlinie + realer Feldkontext) bilden den vollständigen Validierungsnachweis der Bremslicht-Funktion.

*Nebenbefund (ohne Datenwirkung):* Im Bench-Sonderbuild traten kosmetische `esp_task_wdt_reset(): task not found`-Log-Zeilen auf (Bench-Task nicht am TWDT registriert); sie wurden beim CSV-Split über ein striktes Zeilenformat verlustfrei herausgefiltert (0 verworfene echte Datenzeilen). Kein Reset, kein Datenverlust; Normalbetrieb nach der Bench verifiziert wiederhergestellt (`pio test -e native` 77/77 grün).

## 7. Ergänzender Feldtest (Realbetrieb)
30-km/h-Zone; App-Validierungs-CSV (`brake_decel_ms2`, `brake_light_pct` @ 1 Hz) + Beobachtung/Foto → reales Ansprechen des Bremslichts als kontextueller Beleg zur präzisen Bench-Kennlinie. *(auszuführen)*

## 8. Quellen
- SRS **FR-TL-06** (Bremskennlinie), **FR-TL-07** (Notbrems-Blinken, experimentell/deaktiviert), **FR-SAF-01 / FR-STA-04** (Fail-Safe), **NFR-RT-01** (Reaktionszeit ≤ 50 ms), **NFR-TST-02** (Testdaten-Einspeisung) — Project Bible Kap. 2.
- Rohdaten: `docs/Validierung/bench_A_kennlinie_rampe.csv`, `…_B_…`, `…_C_…`, `bench_run_notes.md`.

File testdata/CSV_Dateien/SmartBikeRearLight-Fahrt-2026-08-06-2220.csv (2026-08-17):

# SmartBikeRearLight Fahrt-Export
# schema_version | 2
# geraet | SmartBikeRearLight
# app_version | 1.0
# start_utc | 2026-08-06T20:20:41Z
# ende_utc | 2026-08-06T20:24:06Z
t_s | uhrzeit | device_timestamp_ms | speed_kmph | distanz_km | hoehe_m | pressure_pa | gnss_altitude_m | temperature_c | course_deg | fix_status | sats | hdop | lat | lon | brake_decel_ms2 | brake_light_pct | imu_health | baro_valid | system_state | init_degraded | watchdog_recovered | frame_version
0,0 | 22:20:41 | 219749 | 0,0 | 0,000 | -64,6 | 102104 | 47,5 |  | 211,4 | FIX_OK | 7 | 1,2 | 51,176369 | 6,809710 | 0,27 | 20 | OK | 1 | RUN | 0 | 0 | 2
1,0 | 22:20:42 | 220752 | 0,0 | 0,000 | -64,8 | 102106 | 47,5 |  | 211,4 | FIX_OK | 7 | 1,2 | 51,176369 | 6,809710 | 0,16 | 20 | OK | 1 | RUN | 0 | 0 | 2
2,0 | 22:20:43 | 221756 | 0,0 | 0,000 | -64,5 | 102102 | 47,5 |  | 211,4 | FIX_OK | 7 | 1,2 | 51,176369 | 6,809710 | 0,19 | 20 | OK | 1 | RUN | 0 | 0 | 2
3,0 | 22:20:44 | 222757 | 0,0 | 0,000 | -64,5 | 102102 | 47,5 |  | 211,4 | FIX_OK | 7 | 1,2 | 51,176369 | 6,809710 | 0,60 | 20 | OK | 1 | RUN | 0 | 0 | 2
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

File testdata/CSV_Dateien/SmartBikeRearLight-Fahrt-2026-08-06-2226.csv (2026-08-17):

# SmartBikeRearLight Fahrt-Export
# schema_version | 2
# geraet | SmartBikeRearLight
# app_version | 1.0
# start_utc | 2026-08-06T20:26:09Z
# ende_utc | 2026-08-06T20:28:13Z
t_s | uhrzeit | device_timestamp_ms | speed_kmph | distanz_km | hoehe_m | pressure_pa | gnss_altitude_m | temperature_c | course_deg | fix_status | sats | hdop | lat | lon | brake_decel_ms2 | brake_light_pct | imu_health | baro_valid | system_state | init_degraded | watchdog_recovered | frame_version
0,0 | 22:26:09 | 546945 | 0,0 | 0,000 | -62,8 | 102081 | 42,5 |  | 152,6 | FIX_OK | 12 | 0,8 | 51,178913 | 6,801535 | 0,41 | 20 | OK | 1 | RUN | 0 | 0 | 2
1,0 | 22:26:10 | 547949 | 0,0 | 0,000 | -63,6 | 102091 | 42,5 |  | 152,6 | FIX_OK | 12 | 0,8 | 51,178913 | 6,801535 | 0,27 | 20 | OK | 1 | RUN | 0 | 0 | 2
2,0 | 22:26:11 | 548953 | 0,0 | 0,000 | -63,8 | 102093 | 42,5 |  | 152,6 | FIX_OK | 12 | 0,8 | 51,178913 | 6,801535 | 0,42 | 20 | OK | 1 | RUN | 0 | 0 | 2
3,0 | 22:26:12 | 549955 | 0,0 | 0,000 | -62,8 | 102082 | 42,5 |  | 152,6 | FIX_OK | 12 | 0,8 | 51,178913 | 6,801535 | 0,33 | 20 | OK | 1 | RUN | 0 | 0 | 2
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

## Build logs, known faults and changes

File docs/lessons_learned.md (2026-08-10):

# Lessons Learned

> Von Claude Code pflegbar. Kurze Einträge: Problem → Ursache → Lösung/Erkenntnis.
> Dient als Wissensspeicher für die Thesis (z. B. Kapitel „Herausforderungen").

### macOS: `liblzma`-Fehler beim Toolchain-Build (pioarduino)
**Problem:** PlatformIO bricht beim Laden/Entpacken der pioarduino-Toolchain mit
„Python's lzma module is unavailable/broken" ab.
**Ursache:** pioarduino-Toolchains sind `.tar.xz`-gepackt; PlatformIOs Python
braucht dafür `liblzma`, das auf macOS (insb. Apple Silicon) oft fehlt.
**Lösung:** Homebrew installieren, dann `brew install xz` (liefert
`/opt/homebrew/opt/xz/lib/liblzma.5.dylib`). Danach baut die Toolchain durch.

### Akkubetrieb-Freeze bei angestecktem, aber host-seitig getrenntem USB-Kabel
**Problem:** Bremslicht friert ein (bleibt auf einem Wert stehen), wenn das
USB-Kabel im ESP32 steckt, aber am Host-Ende getrennt ist.
**Ursache:** Floatende VBUS-Leitung → unruhige 3,3-V-Schiene → I²C-/IMU-
Aussetzer. Blinker (eigener Task, nicht von der IMU abhängig) bleibt
unbeeinträchtigt — das Symptom war also regionsspezifisch, nicht global.
**Erkenntnis:** Im echten Akkubetrieb (Kabel komplett ab) nicht reproduzierbar.
„Debug-Setup ≠ Feldbedingung — Validierung stets im realen Betriebszustand."
(s. auch Project Bible Kap. 9.2.)

### ESP32-Core: `Wire.end()` scheitert bei blockiertem I²C-Bus still (No-Recovery-Falle)
**Problem:** Im SDA-Kurzschluss-Fehlerinjektionstest wirkte die I²C-Recovery
(Soft-Reinit, SCL-Clock-Release) zunächst nicht — Log zeigte wiederholt
„Bus already started in Master Mode".
**Ursache:** Im installierten Core (`Wire.cpp`/`esp32-hal-i2c-ng.c`)
verifiziert: `Wire.end()` → `i2cDeinit()` → ESP-IDFs
`i2c_del_master_bus()`; nur bei Erfolg wird der Bus als deinitialisiert
markiert und die Pins per `perimanClearPinBus()` freigegeben. Bei
elektrisch blockiertem Bus kann `i2c_del_master_bus()` fehlschlagen — der
nächste `Wire.begin()` sieht den Bus fälschlich als „schon gestartet" und
wird zum wirkungslosen No-op. Zusätzlich bleiben die Pins dabei
PeriMan-seitig I²C-besessen, wodurch `pinMode()`/`digitalWrite()` in der
SCL-Release-Routine ebenfalls kommentarlos nichts bewirken (PeriMan ruft
vor der Neuzuweisung selbst den — am gleichen Fehler scheiternden —
I²C-Deinit-Callback auf).
**Lösung:** Bus-Recovery mit rohen ESP-IDF-`gpio_*`-Calls (umgehen PeriMan
vollständig) **vor** dem `Wire.end()`-Versuch physisch freimachen; danach
gelingt die eigentliche Deinitialisierung zuverlässig.

### Systematische Hardware-vs-Firmware-Eingrenzung: der BOD-Abschalt-Test als Unterscheidungskriterium
**Problem:** BLE-Start (M5 Teil C2) löste reproduzierbar den Brownout-Detektor
aus (Bootloop bei `NimBLEDevice::init()`). Unklar war lange, ob es sich um
eine Fehlauslösung des Detektors auf einem harmlosen Transienten handelt
oder um einen echten Spannungskollaps — beide Erklärungen erzeugen dasselbe
Symptom (wiederholtes „E BOD" + Reset).
**Vorgehen:** Erst messen, dann schließen — Firmware wurde durch Host-Tests
(75/75) und Bracket-Logging als Ursache ausgeschlossen, bevor an der
Hardware getestet wurde; jede Gegenmaßnahme (Sendeleistung, CPU-Takt,
Kondensatoren an zwei Schienen, geänderte Spannungsquelle) wurde einzeln
getestet und das Ergebnis dokumentiert, auch wenn wirkungslos. Reproduzierbare
Negativergebnisse waren dabei genauso wertvoll wie ein positiver Befund, weil
sie den Hypothesenraum eingrenzen.
**Entscheidendes Unterscheidungskriterium:** Die testweise Deaktivierung des
Brownout-Detektors selbst. Eine reine Fehlauslösung hätte nach dem Wegfall
des Detektors zu unauffälligem Weiterlaufen führen müssen; stattdessen hing
sich das Board an derselben Stelle auf und wurde erst später vom
RTC-/Task-Watchdog zurückgesetzt — ein Beweis für einen echten
Spannungskollaps, nicht für eine überempfindliche Detektion.
**Erkenntnis:** Wenn zwei Erklärungen (Fehlauslösung vs. reales Versagen)
dasselbe Symptom erzeugen, hilft kein weiteres Beobachten des Symptoms
selbst — sondern ein gezielter Kontrollversuch, der die scheinbar
schützende Instanz (hier: den Detektor) selbst entfernt, um zu sehen, ob
das dahinterliegende System tatsächlich versagt. Details:
`docs/ble_brownout_fallstudie.md`.

### Host-Tests allein finden keine Fehlerfall-Bugs am realen Bus
**Problem:** Alle 61 Host-Unit-Tests liefen grün, trotzdem zeigte der reale
SDA-Kurzschluss-Fehlerinjektionstest zwei Bugs (Fehl-Bremslicht durch ein
einzelnes Müll-Sample; wirkungslose I²C-Recovery), die kein Test vorher
gefangen hatte.
**Erkenntnis:** Host-Tests prüfen nur die modellierte Fehlerannahme mit
synthetischen Eingaben, nicht das tatsächliche Verhalten der Hardware-/
Treiberschicht unter einem physischen Fehler. „Debug-Setup ≠ Feldbedingung"
gilt also nicht nur für die Stromversorgung (s. o.), sondern ebenso für
Bus-Fehlerfälle — echte Fehlerinjektion am Gerät bleibt für
sicherheitskritische Pfade unverzichtbar.

### iOS/SwiftData: Aufzeichnung nach App-Neustart lückenlos fortsetzen (Zeitstempel-Kontinuität)
**Problem:** Beim „Weiter fahren" einer nach Absturz wiederhergestellten Fahrt
(AR-DATA-04) beginnt die (simulierte) Frame-Uhr nach dem Neustart wieder bei 0.
Neue Punkte kollidierten dadurch mit den bereits persistierten 1-Hz-Zeitstempeln
(t = 0, 1, 2 …) → der idempotente Append (Schutz gegen Doppel-Zeitstempel beim
Backfill) verwarf sie stillschweigend.
**Lösung:** Die relative Punktzeit `t` über einen `tOffset` fortschreiben, der beim
Fortsetzen auf das letzte gespeicherte `t` gesetzt wird; die erste neue Frame-Zeit
wird zur neuen Basis. Fortgesetzte Punkte laufen so lückenlos hinter den bestehenden
weiter — unabhängig von der nach Neustart zurückgesetzten Geräte-/Mock-Uhr.
**Nebenbefund (SwiftUI):** `.alert` fügt automatisch einen „Cancel"-Button ein,
solange kein Button die `.cancel`-Rolle trägt. Für eine exakt definierte Aktionsmenge
(hier: Abschließen / Verwerfen / Weiter fahren) einem Button bewusst die `.cancel`-
Rolle geben (hier „Weiter fahren"), dann bleibt es bei genau diesen Aktionen.

### App/Aufzeichnung: Der Zeitstempel einer entfernten (Firmware-)Quelle ist keine verlässliche Zeitbasis
**Problem:** Wurde das Rücklicht **mitten in einer laufenden Aufzeichnung** kurz
stromlos geschaltet, sprang nach dem Reconnect die Fahrtdauer auf **1191:44:03**
(≈ 4,29 Mrd. ms) und die Distanz auf **~784 km**; zusätzlich zerlegte es das
Höhenprofil (senkrechte Artefakte, rücklaufende Distanz-Achse). Am realen Gerät
reproduziert.
**Ursache:** Die App leitete Dauer/Distanz aus dem Geräte-Zeitstempel
`timestamp_ms` (uint32 = `millis()` seit Boot) ab. Ein Stromausfall **startet den
ESP32 neu → `millis()` fällt auf ~0 zurück**. Der neue Zeitstempel ist kleiner als
der letzte; die als **vorzeichenlose 32-Bit-Differenz** gerechnete verstrichene Zeit
läuft unter (`neu − alt mod 2^32` ≈ 4,29·10⁹ ms = 1191:44:03). Genau dieser eine
riesige Zeitschritt fließt in die Distanz-Integration (Σ v·dt) → ~784 km, und über
die daraus kumulierte, nicht-monotone Distanz-Achse bricht auch die Höhenprofil-
Grafik.
**Lösung:** Eine reine, host-getestete **`RecordingClock`** (`SmartBikeCore`) führt
eine **monotone** Aufzeichnungszeit: sie erkennt einen Reset (`rawMs < last`) und
re-basiert über einen fortlaufenden Offset, **kappt jeden Schritt auf
`maxSampleDt = 1,5 s`** und verwirft Duplikate. Die Sample-Zeit `t` ist damit immer
monoton und pro Frame ≤ 1,5 s; Dauer (`last.t − first.t`) und Distanz (Σ v·dt)
werden dadurch **automatisch robust**, ohne die `StatisticsEngine` anzufassen
(Fix an der Quelle). 7 neue Swift-Testing-Tests (Reset, Lücke, Duplikat, Backfill,
Monotonie über Reset-Sequenz).
**Erkenntnis:** In einem verteilten System (App + eingebettetes Gerät) darf die Uhr
der *entfernten* Quelle **nicht** als monotone Zeitbasis behandelt werden. Zwei
generische Konsequenzen: (1) vorzeichenlose Zeit-Differenzen gegen Unterlauf
absichern; (2) numerische Integration gegen Ausreißer-`dt` **kappen** — die Kappung
unterschätzt einen langen Ausfall bewusst leicht (sichere Richtung) statt zu
explodieren. Wichtige Unterscheidung: **Funkabriss** (Gerät bleibt an → Backfill aus
dem RAM-Ringpuffer möglich) vs. **Stromausfall** (RAM-Puffer verloren → Lücke
endgültig). Vorher/Nachher am Gerät belegbar (Screenshot 1191:44:03/784 km vs.
korrekte Werte) — geeignet als Validierungs-Abbildung.
### Ein grüner Testlauf beweist nur das, was die Testeingabe abdeckt (Mangel M-01)
**Problem:** Die in FR-TL-06 geforderte Mindesthaltezeit von 300 ms war im
Fahrbetrieb in **allen 14** aufgezeichneten Aktivierungen wirkungslos — obwohl
drei eigens dafür geschriebene Host-Tests grün liefen und die Funktion am
Serial-Bench als validiert galt.
**Ursache:** Der `else`-Zweig der Bremslicht-Zustandsmaschine lief bereits ab
`BRAKE_OFF_MS2` = 1,5 m/s² und überschrieb den für die Haltezeit eingefrorenen
Wert mit `brakeDutyPercent()` — und diese Funktion gibt unterhalb der
Einschaltschwelle von 2,0 m/s² den reinen Schlusslichtwert zurück. Der
„gehaltene" Wert war damit identisch mit dem Wert, gegen den er halten sollte.
Jedes reale Bremssignal durchläuft das Band 1,5…2,0 beim Abklingen.
**Warum die Tests es nicht fanden:** Die drei Haltezeit-Tests speisen
idealisierte Sprünge (5,0 → 0,0) ein und überspringen das Hystereseband
vollständig. Ein vierter Test fährt den Wert 2,0 zwar an, prüft danach aber nur
den *Zustand*, nicht die ausgegebene *Duty*. Die Tests bildeten damit exakt den
Signalverlauf ab, den der Entwickler beim Schreiben der Logik im Kopf hatte —
nicht den, den die Physik erzeugt.
**Erkenntnis:** Grüne Host-Tests belegen die Übereinstimmung der Logik mit den
*modellierten* Eingangssignalen, nicht mit den realen. Der Defekt entstand nicht
durch fehlende Abdeckung (die Zeilen waren abgedeckt), sondern durch eine
Testeingabe, die den kritischen Betriebsbereich systematisch ausließ. Für
Zustandsmaschinen mit Hysterese heißt das konkret: **mindestens ein Testfall muss
das Hystereseband monoton durchlaufen**, nicht darüber hinwegspringen. Gefunden
wurde der Fehler erst durch den Vergleich der aufgezeichneten Ausgangsgröße mit
einer Nachbildung der Zustandsmaschine, gespeist mit den realen Felddaten
(Übereinstimmung 98,53 %) — also durch eine Messung, nicht durch einen Test.

### Diagnoseausgaben innerhalb eines Messfensters verfälschen die gemessene Größe
**Problem:** Die Worst-Case-Schleifenzeit im Fahrbetrieb lag bei 6,7 ms gegenüber
0,651 ms am Prüfstand. Die Spitzen traten exakt periodisch mit 1,00 s auf und
wurden deshalb dem 1-Hz-GNSS-Slot zugeschrieben.
**Ursache der Fehlzuordnung:** Im Aufzeichnungsstand liefen **drei**
Debug-`printf` mit ebenfalls exakt 1 Hz — und alle drei lagen *innerhalb* des
Zeitfensters, aus dem `loop_max_us` gebildet wird. Zusammen rund 173 Byte; bei
115 200 Bd sind das etwa 87 µs je Byte, und sobald der UART-Sendepuffer voll ist,
blockiert `Serial.printf`. Zwei solcher Ausgaben in einem `loop()`-Durchlauf
liegen in derselben Größenordnung wie der gemessene Ausreißer.
**Erkenntnis:** Zwei Vorgänge mit identischer Periode lassen sich aus einer
Zeitreihe grundsätzlich nicht auseinanderhalten — die Zuordnung war eine
plausible Vermutung, kein Befund. Allgemeiner: Eine Messinstrumentierung, die im
Messfenster der Größe liegt, die sie beobachten soll, ist Teil des Messobjekts.
Das ist ein Beobachtereffekt, der in den Daten selbst nicht sichtbar wird. Zwei
Konsequenzen: (1) Instrumentierung entweder aus dem Messfenster herausnehmen oder
ihren Beitrag getrennt beziffern; (2) bei periodischen Störungen immer prüfen, ob
mehr als ein Vorgang dieselbe Periode hat. Der einzige belastbare Weg zur
Trennung wäre ein Kontrollversuch mit und ohne Instrumentierung — dieselbe
Vorgehensweise, die in der BLE-Brownout-Fallstudie zum Ziel führte.

### Mechanische Eigenschaften gehören an die Hardware-Abstraktionsgrenze
**Problem:** Die Lochrasterplatine musste um 180° in ihrer eigenen Ebene gedreht
eingebaut werden. Damit kehren sich a_x, a_y, ω_x und ω_y um; die Bremserkennung
hätte sich invertiert — Bremsen erzeugt kein Bremslicht, Beschleunigen dagegen
schon. Am Schreibtisch wäre das nicht aufgefallen, weil Boot, I²C-Scan,
Telemetrie und Regime-Klassifikation unverändert korrekt erscheinen.
**Lösung:** Die Einbaulage wird als Rotation an der Treibergrenze zurückgerechnet
(`lib/logic/imu_mount_orientation.h`, aufgerufen in `imuRead()`), nicht als
zusätzliches Vorzeichen in der Auswertelogik. Dadurch blieb die gesamte
nachgelagerte Kette unverändert gültig: 126 Host-Tests, der Golden-Vektor, das
Telemetrie-Frame und die komplette App-Seite mussten nicht angefasst werden.
**Zwei Fallstricke, die dabei sichtbar wurden:** (1) Accelerometer **und**
Gyroskop müssen dieselbe Transformation erfahren. Würde nur a_y negiert, gälte
dθ/dt = ω_x nicht mehr und der Komplementärfilter integrierte die Nickschätzung
in die falsche Richtung — unsichtbar im Stand, weil ω_x dort null ist, und erst
während echter Fahrt wirksam. Formal: Die Transformation muss eine echte Rotation
mit Determinante +1 sein, damit das Koordinatensystem rechtshändig bleibt.
(2) Das bereits am Board verifizierte `MOTION_BRAKE_SIGN` darf **nicht**
zusätzlich umgekehrt werden. Die Verifikation erfolgte an den Rohdaten vor dem
Umbau; die Transformation stellt genau diese Konvention wieder her. Ein zweites
Vorzeichen wäre eine Doppelanwendung.
**Erkenntnis:** Eine Eigenschaft des mechanischen Aufbaus ist keine Eigenschaft
des Auswerteverfahrens. Wird sie dort korrigiert, wo sie entsteht — am Übergang
Hardware → Logik —, bleibt alles Nachgelagerte unverändert validiert. Wird sie
weiter hinten korrigiert, repariert man einen Pfad und lässt die übrigen
gespiegelt zurück.

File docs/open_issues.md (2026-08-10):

# Open Issues

> Von Claude Code pflegbar. Kanonische Fassung: Project Bible Kap. 11.
> **Stand 10.08.2026** — nach dem Firmware-Abschluss (Commit `835c7b3`).

## Firmware — abgeschlossen

**Keine offenen Punkte.** Die Firmware ist mit Commit `835c7b3` vom 10.08.2026
abgeschlossen und eingefroren: 126/126 Host-Tests grün, `esp32dev` und
`esp32dev_bench` bauen fehlerfrei, keine `TODO`- oder `FIXME`-Marker im eigenen
Quellcode, Auslieferungsstand auf das Gerät geflasht und im Normalbetrieb
geprüft. Weitere Änderungen sind nur bei einem funktionsverhindernden Fehler
vorgesehen.

Mit diesem Stand geschlossen:

- [x] **Einbaulage-Transformation nach der 180°-Drehung** — `imu_mount_orientation.h`
  an der Treibergrenze, `IMU_MOUNT_SIGN_X/Y/Z` = −1/−1/+1 auf Beschleunigung und
  Drehrate, Determinante +1, eigener Host-Test. `MOTION_BRAKE_SIGN` bleibt bei +1,
  weil die Transformation die vor dem Umbau verifizierte Konvention wiederherstellt.
- [x] **Mangel M-01 — Mindesthaltezeit unwirksam** — der Haltewert wird nur noch
  oberhalb `BRAKE_ON_MS2` nachgeführt. Regressionstest ergänzt, der einen
  Bremsvorgang monoton durch das Hystereseband fahren lässt. Am Gerät bestätigt.
- [x] **Debug-Ausgaben** — alle drei `TODO(temp debug)`-Prints entfernt,
  `DEBUG_SERIAL = false`. Der ungegatete `[R1/R2]`-Print lief mit 1 Hz im
  100-Hz-Task und lag im Messfenster von `loop_max_us` (s. Befund B7).
- [x] **Versionsfestigkeit der Bibliotheken** — alle sechs `lib_deps` gepinnt.
- [x] **Tote Symbole** — `CONFIG_VERSION`, `COMPL_FILTER_ALPHA`, `bleGetMtu()`
  entfernt.
- [x] **Veraltete Kommentare** — `main.cpp`-Kopf („NOCH GERUEST"),
  `MOTION_ANCHOR_WINDOW_S` (0,3 s statt 1,0 s), `tau_slow` (90 s statt 30 s).
- [x] **MPU6050-Konfiguration** (07.08.2026) — `DLPF_CFG = 3` (44 Hz),
  `SMPLRT_DIV = 4` (200 Hz), mit Register-Readback verifiziert.
- [x] **Ruhewert `brake_decel_ms2` ≈ 3,0 m/s²** (07.08.2026) — Ursache
  unkompensierter Gyro-Nullpunktfehler von −4,61 °/s; über ε = b · τ analytisch
  bestätigt.
- [x] **Verankerungsfenster praktisch unerreichbar** (07.08.2026) — Verankerung
  0,3 s, Bias-Kalibrierung über 200 kumulierte STATIC-Abtastungen ohne
  Zusammenhangsforderung.
- [x] **iOS-Arbeitspakete AP0 bis AP8** (07.08.2026) — App Bible v0.22, 89 Tests
  grün, Golden-Vektor-Kreuztest bestanden, am realen iPhone verifiziert.
- [x] **NFR-RT-04 Schleifenzeit** — Prüfstand 0,651 ms, Fahrbetrieb 6,7 ms,
  Anforderung < 10 ms erfüllt. Zur Ursachenzuordnung s. unten.

**Abgegrenzt statt umgesetzt** (Umfangsschnitt 10.08.2026, Begründung und
Auswirkung je Position in Project Bible Kap. 12.2): FR-CFG-02 (serielles
Kalibrier-Interface), FR-CFG-03 (NVS-Konfiguration), Feldverifikation der
IMU-Plausibilitätsschwellen und der BLE-Parameter, Messung des
RF-Wiederholintervalls, I²C-Recovery für den BMP280, SCL-Release am real
hängenden Bus, Teil A des Messprotokolls, Trennung der beiden Ursachen von
Befund B7, Nachmessung des `pitch_rad`-Restwerts, EMV-Frequenzanalyse, weitere
Iteration der drei Normbetrags-Schwellwerte.

## Hardware und Elektronik

- [ ] **Befund B-1, UART-Pegel** — ESP32 treibt GPIO17 mit 3,3 V, L86-Datenblatt
  nennt für RXD1 V_IHmax = 3,1 V. Serienwiderstand 1 kΩ, Teiler 1 k/10 k oder als
  dokumentierte Abweichung führen. Betrieb seit Wochen unauffällig.
- [ ] **Befund B-6, Nennstrom von SW1** — der Schalter führt seit der Korrektur
  der Schalterposition den Akkustrom, Worst Case 1,18 A. Kein Datenblatt für den
  verbauten 8-mm-Drucktaster. Herstellerangabe beschaffen oder Spannungsabfall
  über dem geschlossenen Kontakt unter Last messen.
- [ ] **Befund B-4, fehlende HF-Entkopplung am L86** — dokumentieren oder
  nachrüsten.
- [ ] **BOM-Korrekturen** — GNSS-Antenne Namvo als nicht verbaut kennzeichnen;
  RF-Empfänger einheitlich als SRX882S (nicht „PT2262"); Positionen 10-kΩ-Pull-Down
  (3×), Drucktaster IP65 8 mm, LP103454, Widerstandsnetze RN1–RN3 ergänzen.
- [ ] **Physische Blinker-L/R-Zuordnung** noch nicht festgelegt.
- [ ] **Datenblatt der 3-W-COB-LED** (Vrabocry) fehlt; V_f = 2,2 V ist der
  Mittelwert der Produktangabe 2,0–2,4 V.
- [ ] **Anordnung der Patch-Antenne im Gehäuse** gegen die Datenblattvorgaben
  prüfen.
- [ ] **Lichtstärke (cd) nach § 67** — photometrische Messung, separate
  Hardware-Eigenschaft.
- [ ] **Wirkungsgrad des MT3608 unter realer Last** (angenommen η = 0,90).
- [ ] **Energiebilanz** — Laufzeitangabe ist gerechnet, nicht gemessen
  (NFR-PWR-02).

## Dokumentation und Thesis-Text

- [ ] **`loop_max_us` eindeutig definieren** — Frame-Feld ist das Maximum je
  100-ms-Fenster (App: 53 µs), Nachweis für NFR-RT-04 ist der Worst Case über den
  Lauf (0,651 ms Prüfstand, 6,7 ms Fahrbetrieb). Sonst stehen zwei Zahlen für
  dieselbe Anforderung.
- [ ] **Effektive Ansprechschwelle 2,13 m/s² ausweisen** — die Restdämpfung von
  5,9 % bedeutet, dass die nominelle Schwelle von 2,0 m/s² real erst bei etwa
  2,13 m/s² erreicht wird.
- [ ] **Firmware-Git-Hash im Golden-Vektor** — `testdata/frame_v3_golden.md` um
  `1178017` ergänzen.
- [ ] **Feldanzahl im Golden-Vektor vereinheitlichen** — 41 („unterscheidbare
  Werte", Firmware) vs. 43 (getroffene Felder, App).
- [ ] **Entscheidungs-Kürzel V3-1 bis V3-4** in App Bible und
  `CSV_Format_v3_Validierungsexport.md` nachziehen (die Feldtest-Kürzel E1–E5
  bleiben unverändert).
- [ ] **`docs/Validierung/measurement_log.md` korrigieren** — nicht belegbarer
  Firmware-Hash (`d8a4e75`); die zu weit gefasste Aussage, die Bench speise
  „denselben Signalpfad" wie der Normalbetrieb (`BENCH_MODE` umgeht
  `motion_filter` und `lifecycle_fsm`); die falsche Behauptung einer
  15-prozentigen Ratenverzerrung der Gyro-Integration (`dt_s` wird real gemessen).
- [ ] **Doppelte App-Bible-Fassung** — `App_Bible_v0.21.md` ist ein veralteter
  Schnappschuss neben dem kanonischen `claude/app_bible.md` (v0.22). Vor der
  Abgabe entfernen oder als überholt kennzeichnen.
- [ ] **`ios-app/SmartBikeRearLight/README.md`** fehlt (App Bible Kap. 9).
- [ ] **`project.pbxproj`** trägt eine ungetrackte Änderung (vier entfernte Zeilen
  mit Verweisen auf ein nicht mehr vorhandenes `Info-Setup.md`). Beim
  Abschluss-Commit mitnehmen.
- [ ] **FR-TL-07 Rechtslage** — blinkendes Rücklicht nach § 67 Abs. 4 unzulässig,
  daher default deaktiviert; als Thesis-Zielkonflikt ausformulieren.
- [ ] **„HSD ESP32 IoT Base" als Web-App-Basis** — historischer Punkt, mit der
  Entscheidung für die native iOS-App gegenstandslos. Vor der Abgabe streichen.

## App (iOS)

- [ ] Verlaufs-Gesamtübersicht (AR-HIST-…) — offen.
- [ ] Finale SF-Symbol-Wahl, optionale Höhen-Referenzdruck-Kalibrierung — Future
  Work.

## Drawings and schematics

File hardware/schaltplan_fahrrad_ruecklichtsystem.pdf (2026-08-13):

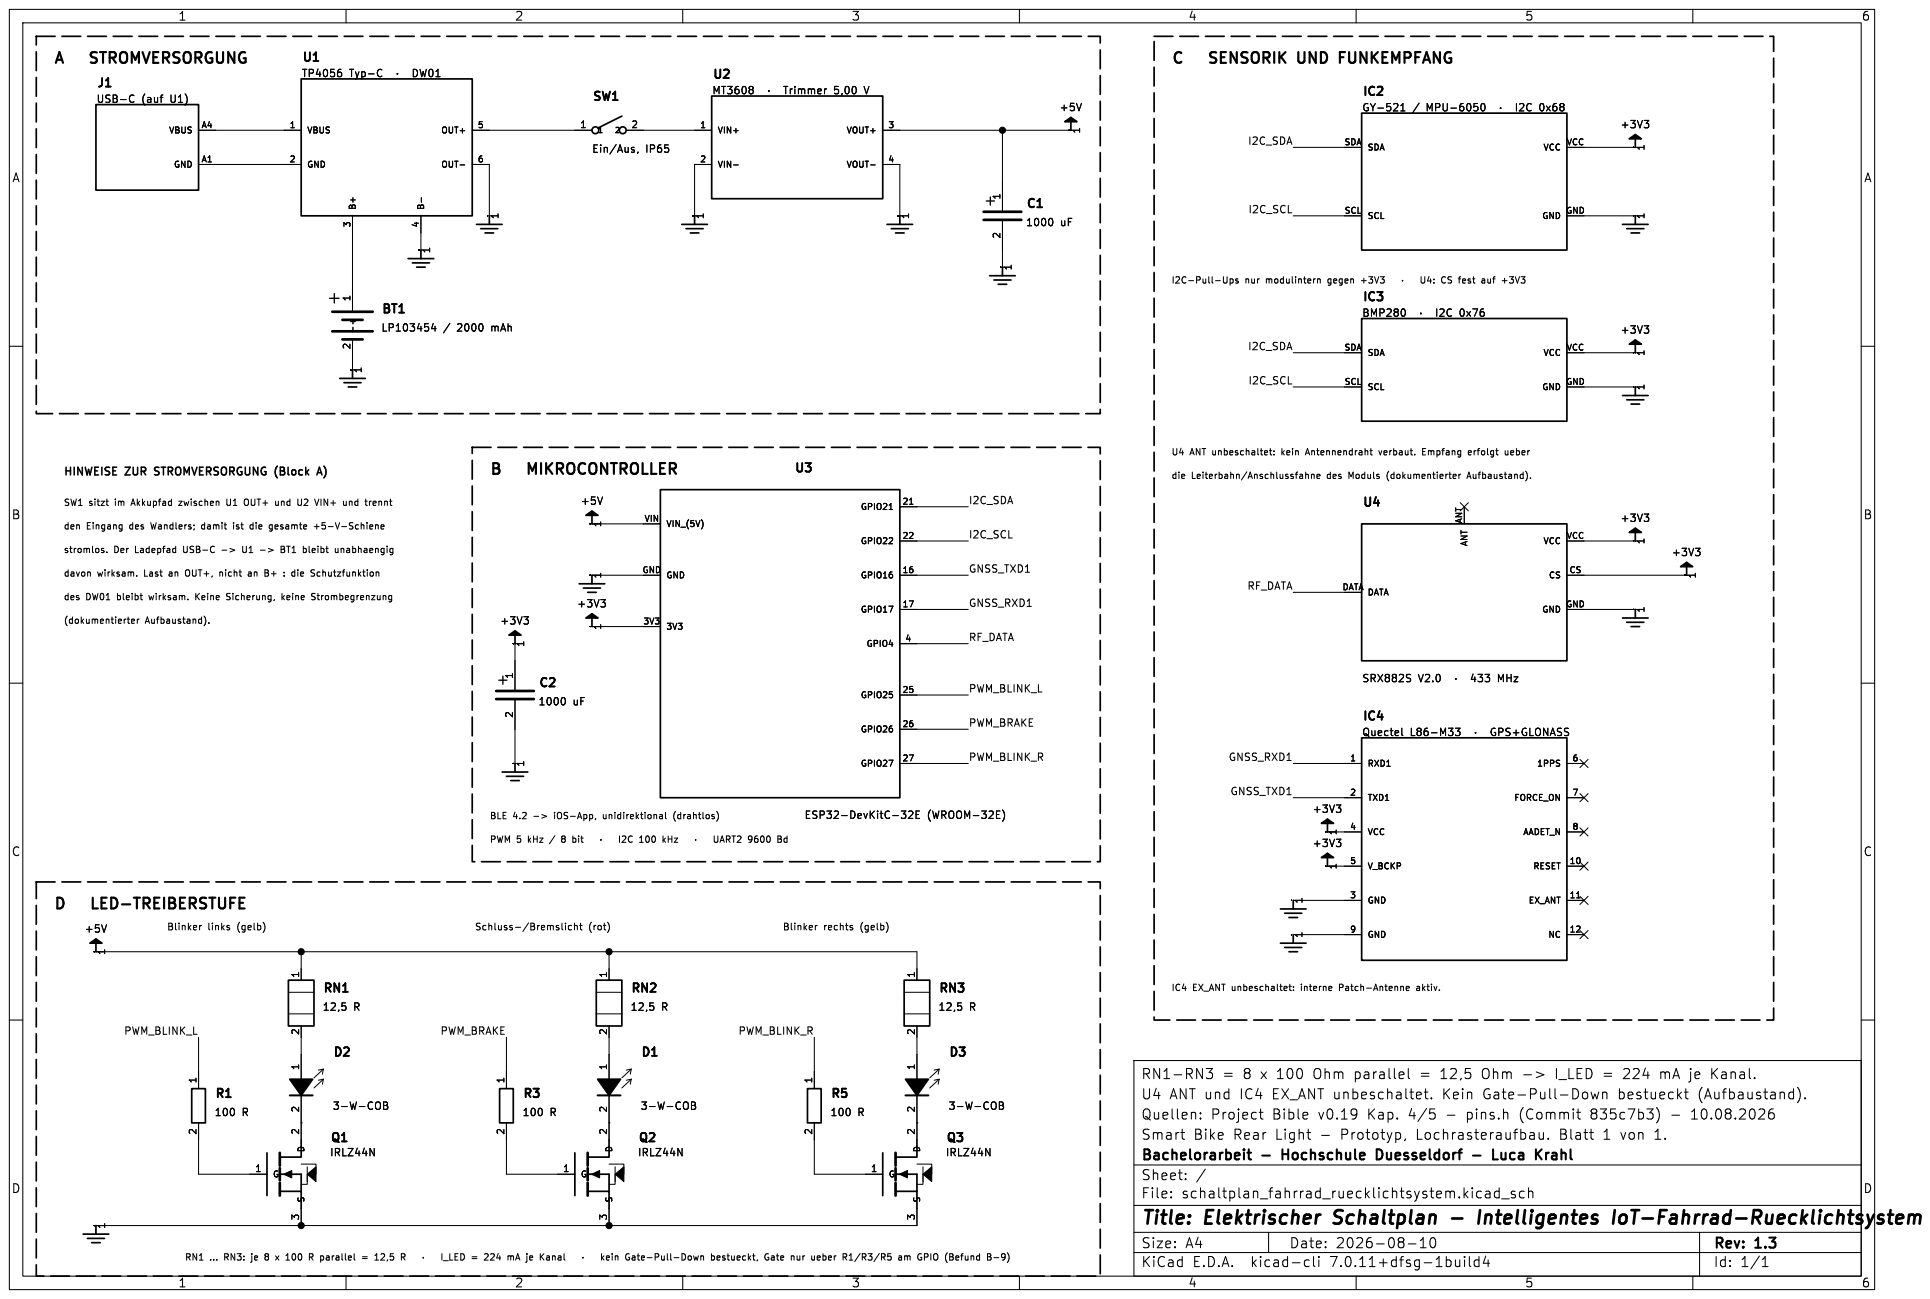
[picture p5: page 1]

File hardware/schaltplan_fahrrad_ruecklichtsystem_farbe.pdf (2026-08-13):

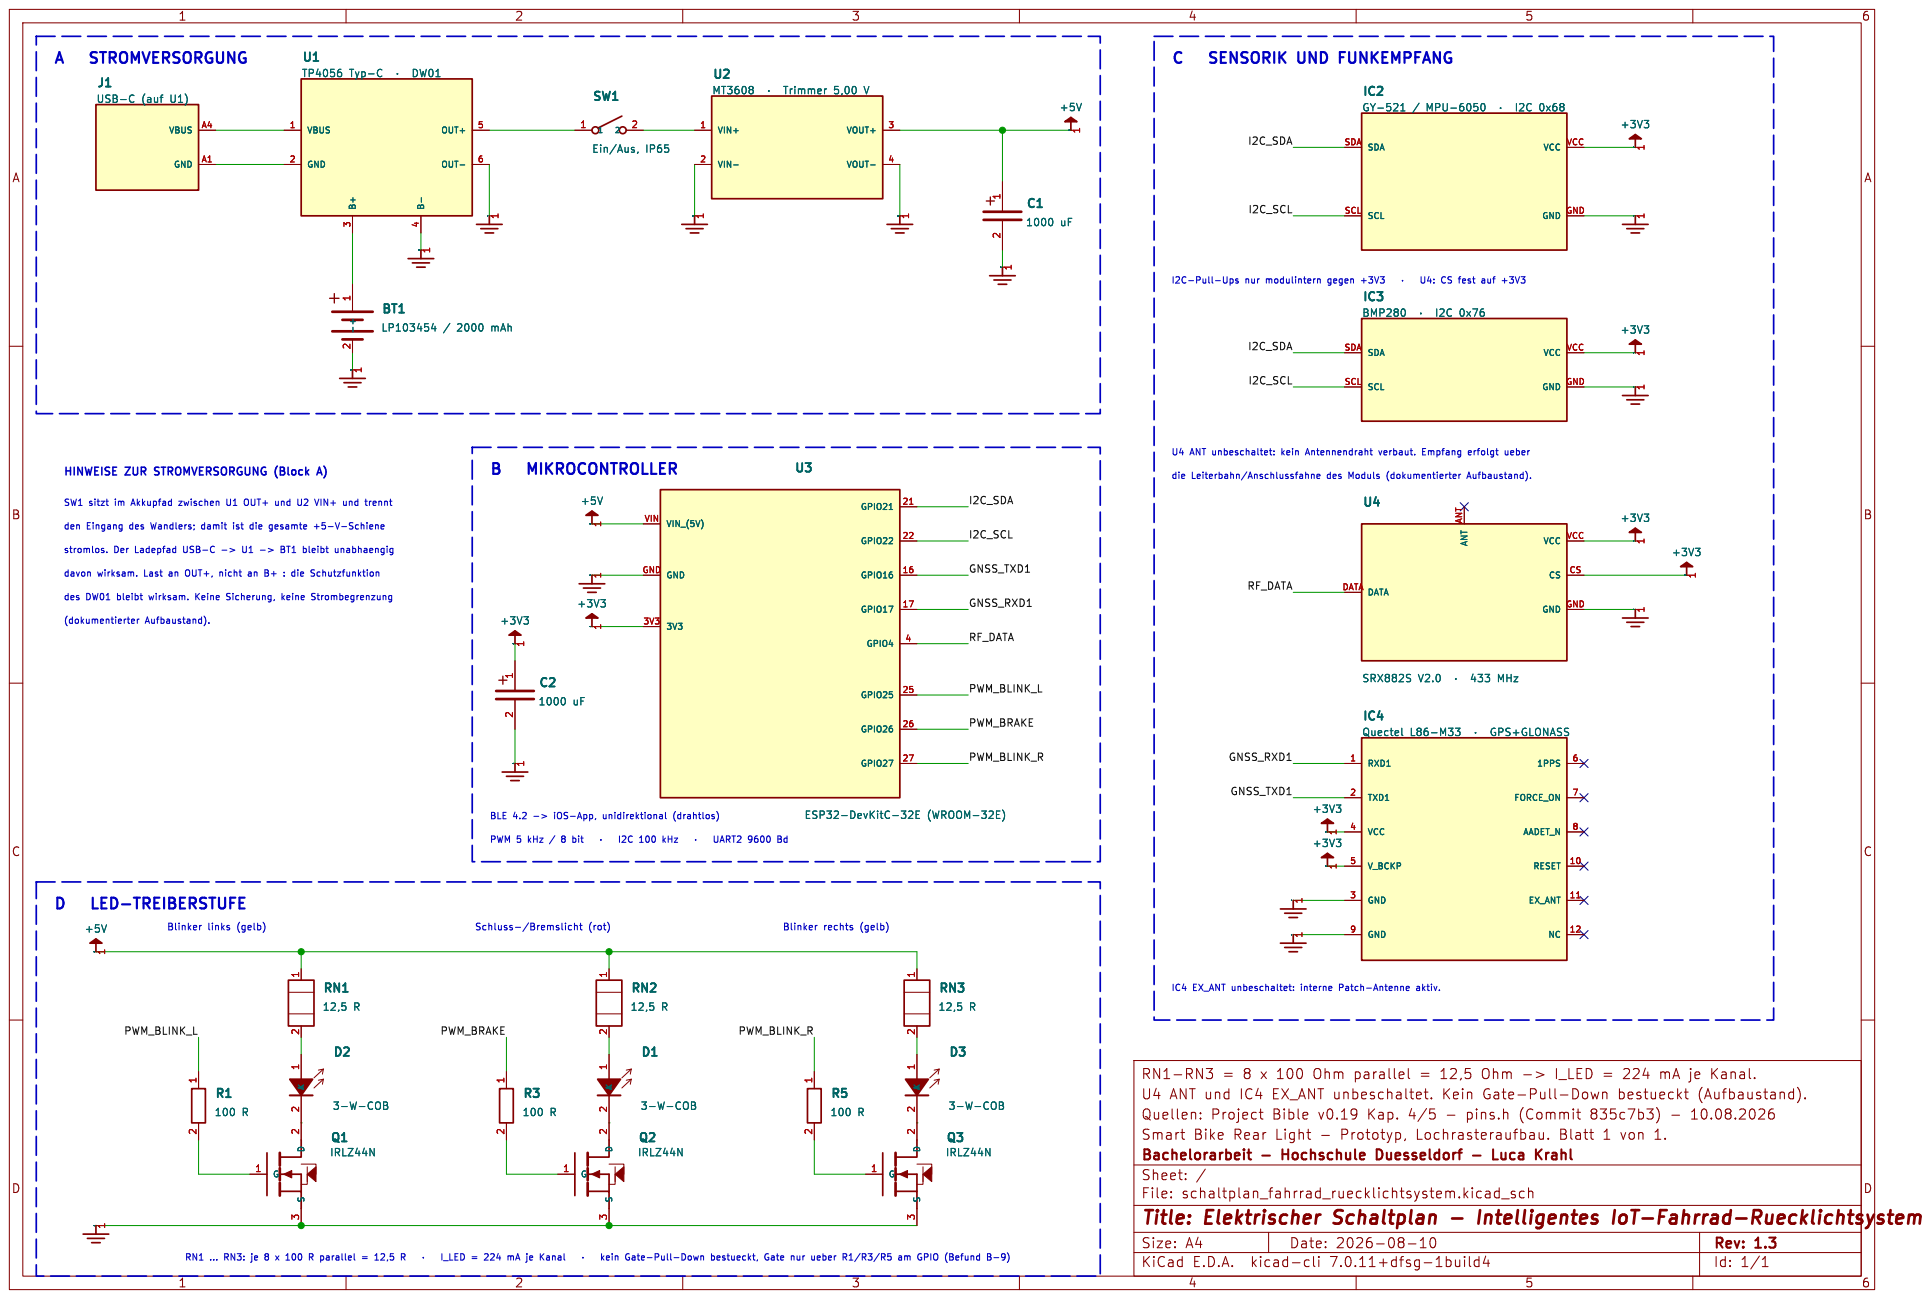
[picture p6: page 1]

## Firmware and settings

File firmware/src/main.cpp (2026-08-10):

// main.cpp — Einstieg & kooperativer Scheduler (Bible Kap. 6.8, NFR-RT-03)
//
// Verdrahtet Treiber (lib/drivers) und Logik (lib/logic) ueber einen
// nicht-blockierenden millis()-Scheduler zu den vier Regionen R1..R4 (Bible
// Kap. 6.6).
//
// WICHTIG: kein delay() im Betrieb. Jeder Task-Schritt bleibt kurz (< 10 ms
// Worst-Case-Loop, NFR-RT-04).

#include <Arduino.h>
#include <Wire.h>
#include <esp_task_wdt.h>     // FR-SAF-03 (Task-Watchdog)
#include <esp_system.h>       // FR-SAF-03 (esp_reset_reason())
#include "pins.h"
#include "config.h"
#include "led_output.h"       // drivers  (R2/R3 Aktorik, CON-02)
#include "imu_driver.h"       // drivers  (R4 IMU, FR-SNS-01/02/03)
#include "bmp280_driver.h"    // drivers  (R4 Baro, FR-SNS-01/02/03)
#include "gnss_driver.h"      // drivers  (R4 GNSS/L86, FR-SNS-01/02)
#include "rf_input.h"         // drivers  (RF-Empfang, FR-RF-01)
#include "ble_telemetry.h"    // drivers  (R4 BLE-Transport, FR-TEL-01, FR-SYS-04)
#include "lifecycle_fsm.h"    // logic    (R1)
#include "tail_light_fsm.h"   // logic    (R2)
#include "motion_filter.h"    // logic    (R4->R2, Komplementaerfilter)
#include "imu_health.h"       // logic    (R4 IMU-Gesundheit, FR-SNS-04/05, FR-STA-04)
#include "button_decoder.h"   // logic    (RF-Tastenerkennung, FR-RF-02/03/04)
#include "blinker_fsm.h"      // logic    (R3, FR-BLK-01..09)
#include "gnss_fix.h"         // logic    (R4 GNSS-Fix-Bewertung, FR-TEL-05)
#include "telemetry_frame.h"  // logic    (R4 Telemetrie-Frame, FR-TEL-02/03/06)
#include "telemetry_buffer.h" // logic    (R4 RAM-Ringpuffer, FR-TEL-04)
#include "telemetry_window_agg.h"  // logic (v3 Fensteraggregation, docs/BLE_Frame_v3_Schnittstelle.md)
#include "gnss_speed_ref.h"        // logic (v3 GNSS-Referenz, E1, rein beobachtend, E5)

// PWM-Kanal-Zuordnung erfolgt ueber ledcAttach() (Core v3.x, CON-02).

// ---- kooperativer Scheduler: einfache Task-Zeitstempel -------------------
static uint32_t t_imu = 0, t_baro = 0, t_gnss = 0, t_tele = 0;

// R1 (Lebenszyklus) und R2 (Ruecklicht) als reine Logik-Instanzen; werden von
// taskLifecycleAndTailLight() 100 Hz getickt (s. u.).
static logic::LifecycleFsm lifecycleFsm;
static logic::TailLightFsm tailLightFsm;
static logic::MotionFilter motionFilter;
static uint32_t t_motion_prev_ms = 0;  // fuer dt_s der Komplementaerfilter-Eingabe

// IMU-Gesundheit (FR-SNS-04/05, FR-STA-04): getrennt von R1/lifecycleFsm
// gefuehrt, da dessen degraded-Flag laut lifecycle_fsm.h bewusst nur das
// INIT-Ergebnis abbildet (FR-STA-06: kein Ruecksprung nach RUN). Ein
// Laufzeit-Sensorausfall gated hier ausschliesslich R2 (s. u.).
static logic::ImuHealth imuHealth;
static bool imu_was_healthy_last_cycle_ = false;  // fuer motionFilter-Reset beim Uebergang

// Letzter IMU-Gesundheitsstatus, vorgehalten fuer die spaetere Telemetrie
// (FR-TEL-03), die Sensor-Fehler als eigenes Flag an die App melden soll.
static logic::ImuHealthOutput lastImuHealth{};

// Letzter von taskLifecycleAndTailLight() ermittelter Lebenszyklus-Zustand.
// Vorbelegt mit Init: Tastendruecke werden verworfen, bis R1 erstmals RUN
// liefert (FR-BLK-09-Gating, s. taskBlinker()).
static logic::SystemState lastSystemState = logic::SystemState::Init;

// RF-Tastenerkennung (Sub-FSM vor R3) + Blinker-FSM (R3).
static logic::ButtonDecoder buttonDecoder;
static logic::BlinkerFsm    blinkerFsm;

// Von taskRf() gesetztes, von taskBlinker() im selben loop()-Durchlauf genau
// einmal konsumiertes Ereignis (taskRf laeuft vor taskBlinker, s. loop()).
static logic::ButtonEvent pendingButtonEvent = logic::ButtonEvent::NONE;

// FR-SAF-03: true, wenn dieser Boot durch einen Watchdog-/Panic-Reset
// ausgeloest wurde (in setup() einmalig gesetzt). Vorgehalten fuer die
// spaetere Telemetrie (FR-TEL-03) -- ein WDT-Reset im Fahrbetrieb bedeutet
// einen kurzen Neustart (Init-Blink -> Schlusslicht), akzeptierte
// Fail-Safe-Ausnahme (FR-SAF-01).
static bool bootRecoveredFromWatchdog = false;

// ---- Telemetrie (M5 Teil C2, FR-TEL-01..04) -------------------------------
// Letzte Sensor-/Statuswerte, file-scope vorgehalten (Muster wie
// lastImuHealth oben) -- taskTelemetry() liest hieraus, statt Sensoren
// erneut/asynchron abzufragen. accel/gyro werden nur bei read_ok
// aktualisiert (letzte tatsaechliche Messung, keine Nullen bei einem
// transienten I2C-Blip, s. taskLifecycleAndTailLight()); brake_decel_ms2
// dagegen bewusst jeden Zyklus (roher motion_filter-Wert inkl. der durch
// !healthy_this_cycle erzwungenen 0, s. telemetry_frame.h Feld-Kommentar).
static drivers::ImuSample lastImuSample{};
static float lastDecelMs2 = 0.0f;
static bool lastInitDegraded = false;
static drivers::BaroSample lastBaroSample{};
static bool lastBaroValid = false;
static drivers::GnssData lastGnssData{};
static logic::GnssFixStatus lastGnssFix = logic::GnssFixStatus::NO_DATA;
// Tatsaechlich kommandierte Ruecklicht-Duty (derselbe Wert wie an
// drivers::setDutyPercent() uebergeben) -- im Gegensatz zu lastDecelMs2
// bereits durch tail_light_fsm gegatet, s. telemetry_frame.h Feld-Kommentar
// zu brake_light_pct.
static uint8_t lastBrakeLightPct = 0;

// RAM-Ringpuffer (FR-TEL-04, NFR-RES-01) fuer Frames ohne BLE-Verbindung
// bzw. als Reconnect-Backfill-Quelle (s. taskTelemetry()).
static logic::TelemetryBuffer telemetryBuffer;

// ---- v3-Erweiterung (docs/BLE_Frame_v3_Schnittstelle.md) ------------------
// Fensteraggregation der 100-Hz-Groessen zwischen zwei Telemetrie-Frames
// (Kap. 3.2/3.3) -- gefuettert in taskLifecycleAndTailLight(), ausgelesen +
// zurueckgesetzt in taskTelemetry().
static logic::TelemetryWindowAgg telemetryWindowAgg;

// Dauer des VORHERIGEN loop()-Durchlaufs in us (micros(), NFR-RT-04, s.
// loop()). Bewusst ein Zyklus "alt": der aktuelle Durchlauf ist zum
// Zeitpunkt des add()-Aufrufs in taskLifecycleAndTailLight() (fruehzeitig
// in loop(), s. u.) noch nicht abgeschlossen. Bei einem 100-Hz-Fenster mit
// ~10 Samples ist dieser Ein-Zyklus-Versatz fuer ein Maximum irrelevant.
static uint32_t lastLoopDurationUs = 0;

// GNSS-Referenzbeschleunigung (E1, BEOBACHTEND, E5): wirkt an keiner Stelle
// auf motion_filter/tail_light_fsm zurueck, s. gnss_speed_ref.h. Nur fuer
// die v3-Telemetrie vorgehalten.
static logic::GnssSpeedRef gnssSpeedRef;
static logic::GnssSpeedRefOutput lastGnssSpeedRef{};
static uint32_t t_gnss_speed_ref_prev_ms = 0;  // fuer real gemessenes dt_s zwischen Fixes

// ------------------------------------------------------------------------
// Tasks — je Region die Verdrahtung von Treiber und Logik.
// ------------------------------------------------------------------------
static void taskLifecycleAndTailLight() {
  // 100 Hz. Tickt R1 (Lebenszyklus) + R2 (Ruecklicht). Sicherheitskritisch,
  // Reaktionszeit <= 50 ms (NFR-RT-01).
  const uint32_t now = millis();

  drivers::ImuSample raw{};
  const bool read_ok = drivers::imuRead(raw);
  const logic::ImuHealthOutput health = imuHealth.update(
      read_ok, raw.accel_x_ms2, raw.accel_y_ms2, raw.accel_z_ms2, raw.gyro_x_rads, now);
  lastImuHealth = health;  // fuer spaetere Telemetrie (FR-TEL-03/FR-STA-04)
  if (read_ok) {
    lastImuSample = raw;  // letzte tatsaechliche Messung, s. Kommentar oben
  }

  // Zwei bewusst getrennte Gates, auch wenn sie sich aktuell pro Zyklus
  // decken: motionFilter wird an der reinen Zyklus-Gesundheit (read_ok &&
  // plausible) gespeist, R2 weiter unten dagegen am state-basierten
  // degraded-Flag -- so bleibt ein spaeterer Debounce-/Hysterese-Umbau von
  // "degraded" ohne Wirkung auf die Filter-Fuetterung.
  const bool healthy_this_cycle = read_ok && health.plausible;

  float decel_ms2 = 0.0f;
  if (healthy_this_cycle) {
    if (!imu_was_healthy_last_cycle_) {
      // Nach einer Ausfall-/Recovery-Phase: alten Neigungswinkel verwerfen
      // und Zeitbasis neu setzen, sonst wuerde ein grosser dt_s-Sprung bzw.
      // ein waehrenddessen veralteter Winkel eine falsche Brems-
      // Beschleunigung vortaeuschen (s. motion_filter::reset()).
      motionFilter.reset();
      t_motion_prev_ms = now;
    }
    float dt_s = (now - t_motion_prev_ms) / 1000.0f;
    t_motion_prev_ms = now;
    // Defensive Begrenzung (1..50 ms): ein Ausreisser nach einer Blockade
    // (z. B. I2C-Recovery-Zyklus) soll die Gyro-Integration nicht
    // "sprengen"; dt_s ist der real gemessene Abtastabstand, keine
    // Konstante -- ein einzelner grosser Sprung waere sonst ungebremst.
    if (dt_s < 0.001f) dt_s = 0.001f;
    if (dt_s > 0.050f) dt_s = 0.050f;
    decel_ms2 = motionFilter.update(
        {raw.accel_x_ms2, raw.accel_y_ms2, raw.accel_z_ms2, raw.gyro_x_rads, dt_s});

    // v3-Fensteraggregation (Vertrag Kap. 3.2/3.3): norm_delta ist hier
    // bewusst ‖a‖-g (accel_norm()-g), NICHT motionFilter.normDelta() --
    // Letzteres liefert den Jerk (Namenskollision, s. Hinweis in
    // telemetry_window_agg.h). Nur bei healthy_this_cycle gefuettert, sonst
    // waeren accel_norm()/regime() nicht von diesem Zyklus.
    constexpr float kGravityMs2 = 9.80665f;
    telemetryWindowAgg.add(dt_s, motionFilter.accel_norm() - kGravityMs2,
                            motionFilter.normDelta(), motionFilter.regime(), lastLoopDurationUs);
  }
  imu_was_healthy_last_cycle_ = healthy_this_cycle;
  lastDecelMs2 = decel_ms2;  // fuer Telemetrie: roher Filterwert, s. Feld-Kommentar telemetry_frame.h

  if (health.request_recovery) {
    drivers::imuRecoverStage(health.recovery_stage);
  }

  const bool critical_sensors_ready = drivers::imuIsReady();
  const logic::LifecycleOutput sys = lifecycleFsm.update(critical_sensors_ready, now);
  lastInitDegraded = sys.degraded;  // fuer Telemetrie (FR-TEL-03)

  // FR-STA-04 Fail-Safe: auf JEDEM ungesunden Zyklus explizit 0 -- nicht
  // erst ab "degraded" (das kippt erst nach IMU_FAIL_LIMIT Zyklen). Schon
  // waehrend dieser Zaehlphase soll tail_light_fsm keinen frischen Wert
  // bekommen. Zusaetzlich: escalation_trusted verlangt IMU_ESCALATION_
  // CONFIRM_CYCLES aufeinanderfolgende plausible Zyklen, bevor ein
  // Bremswert ueberhaupt durchgereicht wird -- ein einzelnes Muell-aber-
  // plausibles Sample (Fehlerinjektionstest SDA-Kurzschluss) darf sonst
  // sofort eine Bremseskalation ausloesen. decel_ms2 ist strukturell
  // bereits 0, wenn !healthy_this_cycle (frische lokale Variable, nur im
  // healthy_this_cycle-Zweig oben befuellt) -- hier trotzdem explizit an
  // beide Bedingungen gebunden, damit die Zusicherung im Code sichtbar ist.
  // tail_light_fsm faellt dadurch ueber seine bestehende Hysterese/
  // Mindesthaltezeit von selbst sicher auf Dauer-Schlusslicht zurueck --
  // R2 selbst bleibt unveraendert, muss vom IMU-Zustand nichts wissen.
  const float tail_input =
      (healthy_this_cycle && health.escalation_trusted) ? decel_ms2 : 0.0f;
  const logic::TailLightOutput tl = tailLightFsm.update(tail_input, sys.state, now);
  drivers::setDutyPercent(PIN_BRAKE_LIGHT, tl.duty_pct);
  lastBrakeLightPct = tl.duty_pct;  // fuer Telemetrie, s. Kommentar bei der Deklaration
  lastSystemState = sys.state;  // fuer FR-BLK-09-Gating in taskBlinker()
}

static void taskBaro() {
  // Task-Slot 10 Hz (s. loop()), BMP280-FORCED-Zyklus laeuft bewusst
  // langsamer (BARO_FORCED_CYCLE_MS, ~1 Hz): Trigger und Read sind auf zwei
  // aufeinanderfolgende Zyklen entkoppelt, dazwischen schlaeft der Sensor
  // (Selbsterwaermung minimiert). Kein blockierendes Warten: bmp280Read()
  // liest immer eine laengst abgeschlossene Messung (Konversionszeit ~6 ms
  // << BARO_FORCED_CYCLE_MS, s. bmp280_driver.cpp).
  static uint32_t t_cycle = 0;
  static bool measurement_pending = false;

  const uint32_t now = millis();
  if (now - t_cycle < BARO_FORCED_CYCLE_MS) {
    return;
  }
  t_cycle = now;

  if (!drivers::bmp280IsReady()) {
    lastBaroValid = false;  // optionaler Sensor (FR-STA-05), fuer Telemetrie
    return;                 // kein Effekt auf Licht/Blinker
  }

  if (measurement_pending) {
    lastBaroSample = drivers::bmp280Read();
    lastBaroValid = true;
  }
  drivers::bmp280TriggerMeasurement();
  measurement_pending = true;
}

static void taskGnss() {
  // 1 Hz (PERIOD_GNSS_MS, s. loop()). NMEA wird nicht hier, sondern jeden
  // loop()-Durchlauf per gnssPump() geparst (s. loop()) — hier wird nur
  // der aktuelle Stand gelesen und bewertet. Optionaler Sensor (FR-STA-05):
  // kein Fix/keine Daten beeinflussen Licht/Blinker nicht.
  lastGnssData = drivers::gnssRead();
  lastGnssFix = logic::gnssFixStatus(lastGnssData.location_valid, lastGnssData.location_age_ms,
                                      lastGnssData.sats, lastGnssData.chars_processed);

  // v3 (E1, BEOBACHTEND/E5): grobe Referenzbeschleunigung aus aufeinander-
  // folgenden 1-Hz-Fixes -- wirkt an keiner Stelle auf motion_filter/
  // tail_light_fsm zurueck (s. gnss_speed_ref.h). dt_s ist die real
  // gemessene Zeit seit dem letzten taskGnss()-Aufruf, nicht PERIOD_GNSS_MS
  // (gleiches Muster wie motionFilter, s. taskLifecycleAndTailLight()); der
  // erste Aufruf liefert einen unplausibel grossen dt_s, ist aber
  // wirkungslos, da has_prev_ dort ohnehin noch false ist.
  const uint32_t now_gnss = millis();
  const float gnss_dt_s = (now_gnss - t_gnss_speed_ref_prev_ms) / 1000.0f;
  t_gnss_speed_ref_prev_ms = now_gnss;
  lastGnssSpeedRef = gnssSpeedRef.update({lastGnssData.speed_kmph / 3.6f, lastGnssData.sats,
                                          lastGnssData.hdop, lastGnssData.location_valid, gnss_dt_s});
}

static void taskBlinker() {
  // Kein fester Task-Takt: laeuft jeden loop()-Durchlauf, direkt nach taskRf()
  // (s. loop()), damit ein erkanntes Ereignis genau einmal verarbeitet wird.
  const uint32_t now = millis();

  // FR-BLK-09: RF-Blinkerbefehle erst ab RUN wirksam, waehrend INIT verworfen.
  const logic::ButtonEvent event =
      (lastSystemState == logic::SystemState::Run) ? pendingButtonEvent
                                                      : logic::ButtonEvent::NONE;
  pendingButtonEvent = logic::ButtonEvent::NONE;  // genau einmal konsumiert

  const logic::BlinkerOutput out = blinkerFsm.update(event, now);
  drivers::setDutyPercent(PIN_BLINK_LEFT,  out.left_on  ? 100 : 0);
  drivers::setDutyPercent(PIN_BLINK_RIGHT, out.right_on ? 100 : 0);
}

static void taskRf() {
  // Kein fester Task-Takt: laeuft jeden loop()-Durchlauf (FR-RF-01,
  // kontinuierliche Ueberwachung). Laeuft vor taskBlinker() (s. loop()).
  const uint32_t now = millis();
  const drivers::RfSignal rf = drivers::rfRead();
  pendingButtonEvent = buttonDecoder.update(rf.has_code, rf.code, now);
}

static void taskTelemetry() {
  // 10 Hz (FR-TEL-02). Frame aus den zuletzt gesampelten Werten bauen und je
  // nach BLE-Zustand direkt senden oder puffern (FR-TEL-01/04).
  const uint32_t now = millis();

  logic::TelemetryFrame frame{};
  frame.timestamp_ms = now;

  frame.accel_x_ms2 = lastImuSample.accel_x_ms2;
  frame.accel_y_ms2 = lastImuSample.accel_y_ms2;
  frame.accel_z_ms2 = lastImuSample.accel_z_ms2;
  frame.gyro_x_rads = lastImuSample.gyro_x_rads;
  frame.gyro_y_rads = lastImuSample.gyro_y_rads;
  frame.gyro_z_rads = lastImuSample.gyro_z_rads;
  frame.brake_decel_ms2 = lastDecelMs2;

  frame.pressure_pa = lastBaroSample.pressure_pa;
  frame.temperature_c = lastBaroSample.temperature_c;

  frame.lat = lastGnssData.lat;
  frame.lon = lastGnssData.lon;
  frame.speed_kmph = lastGnssData.speed_kmph;
  frame.course_deg = lastGnssData.course_deg;
  frame.altitude_m = lastGnssData.altitude_m;
  frame.sats = lastGnssData.sats;
  frame.hdop = lastGnssData.hdop;
  frame.utc_year = lastGnssData.year;
  frame.utc_month = lastGnssData.month;
  frame.utc_day = lastGnssData.day;
  frame.utc_hour = lastGnssData.hour;
  frame.utc_minute = lastGnssData.minute;
  frame.utc_second = lastGnssData.second;

  frame.system_state = static_cast<uint8_t>(lastSystemState);
  frame.init_degraded = lastInitDegraded;
  frame.imu_health_state = static_cast<uint8_t>(lastImuHealth.state);
  frame.baro_valid = lastBaroValid;
  frame.gnss_fix_status = static_cast<uint8_t>(lastGnssFix);
  frame.watchdog_recovered = bootRecoveredFromWatchdog;
  frame.brake_light_pct = lastBrakeLightPct;

  // v3 (docs/BLE_Frame_v3_Schnittstelle.md Kap. 3.2). gnss_accel_ms2 ist bei
  // !valid IMMER 0.0f (nie NaN, s. Feld-Kommentar telemetry_frame.h).
  frame.gnss_accel_ms2 = lastGnssSpeedRef.valid ? lastGnssSpeedRef.accel_ms2 : 0.0f;
  frame.gnss_accel_valid = lastGnssSpeedRef.valid;
  frame.pitch_rad = motionFilter.pitch_rad();
  frame.gyro_bias_rads = motionFilter.gyroBiasRads();
  frame.bias_calibrated = motionFilter.biasCalibrated();

  const logic::WindowAggSnapshot windowSnap = telemetryWindowAgg.snapshotAndReset();
  frame.norm_delta_min = windowSnap.norm_delta_min;
  frame.norm_delta_max = windowSnap.norm_delta_max;
  frame.jerk_max = windowSnap.jerk_max;
  frame.regime_static_n = windowSnap.regime_static_n;
  frame.regime_dynamic_n = windowSnap.regime_dynamic_n;
  frame.regime_shock_n = windowSnap.regime_shock_n;
  frame.dt_max_ms = windowSnap.dt_max_ms;
  frame.loop_max_us = windowSnap.loop_max_us;


  uint8_t bytes[logic::TELEMETRY_FRAME_SIZE];
  logic::telemetryFrameSerialize(frame, bytes);

  if (!drivers::bleIsConnected()) {
    telemetryBuffer.push(bytes);  // FR-TEL-04: ohne Verbindung puffern
    return;
  }

  if (telemetryBuffer.empty()) {
    drivers::bleNotify(bytes, logic::TELEMETRY_FRAME_SIZE);  // Live-Fall: direkt senden
    return;
  }

  // Reconnect-Backfill: frisches Frame hinten anstellen (haelt die FIFO-
  // Chronologie strikt, kein zweiter Strom noetig), dann bis zu
  // BLE_BACKFILL_FRAMES_PER_TICK aelteste Frames nachliefern -- das holt
  // 60 s Backlog binnen weniger Sekunden auf, ohne die Live-Rate zu stoeren
  // (dieser Block laeuft weiterhin nur einmal pro 100-ms-Tick).
  telemetryBuffer.push(bytes);
  uint8_t backlog[logic::TELEMETRY_FRAME_SIZE];
  for (uint8_t i = 0; i < BLE_BACKFILL_FRAMES_PER_TICK; ++i) {
    if (telemetryBuffer.empty()) {
      break;
    }
    telemetryBuffer.pop(backlog);
    if (!drivers::bleNotify(backlog, logic::TELEMETRY_FRAME_SIZE)) {
      // Sende-Queue des BLE-Stacks voll (selten): Frame nicht verlieren,
      // aber auch nicht auf einen Retry innerhalb dieses Ticks warten
      // (NFR-RT-04). Wird ans Pufferende zurueckgelegt -- unter dieser
      // seltenen Kongestion nicht mehr streng chronologisch, dafuer ohne
      // eigene peek()-Erweiterung der bereits getesteten TelemetryBuffer-API.
      telemetryBuffer.push(backlog);
      break;
    }
  }
}
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
void loop() {
  delay(1000);  // Bench beendet -- Idle, kein Normalbetrieb in diesem Build
}
#endif  // BENCH_MODE

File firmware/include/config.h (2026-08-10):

// config.h — Compile-Zeit-Defaults & Konstanten (Bible Kap. 2, FR-CFG)
// Kalibrierwerte (unten markiert) sind Uebersetzungszeit-Konstanten; eine
// Aenderung erfordert Neuuebersetzung. FR-CFG-02 (serielles Kalibrier-
// Interface) und FR-CFG-03 (Laufzeit-Konfiguration aus NVS) sind nicht Teil
// des Arbeitsumfangs (Umfangsschnitt 10.08.2026, s. Project Bible Kap. 12).
#pragma once
#include <stdint.h>

// ---- Zustandsmaschine / Timing (fest) ------------------------------------
constexpr uint32_t INIT_TIMEOUT_MS      = 5000;   // FR-STA-01
constexpr uint32_t BLINKER_TIMEOUT_MS   = 60000;  // FR-BLK-03 (Selbstabschaltung)
constexpr uint32_t LONGPRESS_MS         = 5000;   // FR-BLK-04/07 (Warnblinker)
constexpr uint32_t RF_RELEASE_TIMEOUT_MS = 150;   // FR-RF-03 (Erstauslegung; im Feldbetrieb ohne Fehlfunktion bestaetigt, systematische Messung nicht Teil des Arbeitsumfangs)

// ---- LED / PWM (fest, Norm) ----------------------------------------------
constexpr uint32_t PWM_FREQ_HZ          = 5000;   // CON-02
constexpr uint8_t  PWM_RESOLUTION_BITS  = 8;      // 0..255
constexpr uint8_t  TAILLIGHT_DUTY_PCT   = 20;     // FR-TL-04 Schlusslicht-Grundhelligkeit
constexpr float    BLINK_FREQ_HZ        = 1.5f;   // FR-BLK-08 (ECE R6)
constexpr uint8_t  BLINK_DUTY_PCT       = 50;     // FR-BLK-08 Zeit-Duty-Cycle
constexpr float    INIT_BLINK_FREQ_HZ   = 2.0f;   // FR-TL-03 Diagnose-Blinken
constexpr uint8_t  INIT_BLINK_DUTY_PCT  = 50;     // FR-TL-03 Zeit-Duty-Cycle
constexpr uint8_t  INIT_BLINK_HIGH_PCT  = 50;     // FR-TL-03, C3.1 Helligkeits-Amplitude oben (unten 0 %)
constexpr float    ESS_BLINK_FREQ_HZ    = 4.0f;   // FR-TL-07 (experimentell)
constexpr uint8_t  ESS_BLINK_DUTY_PCT   = 50;     // FR-TL-07 Zeit-Duty-Cycle (analog INIT_BLINK_DUTY_PCT)

// ---- Bremskennlinie — KALIBRIERWERTE (Uebersetzungszeit-Konstanten, FR-CFG-01) -----
constexpr float BRAKE_ON_MS2    = 2.0f;   // FR-TL-06 Einschaltschwelle
constexpr float BRAKE_OFF_MS2   = 1.5f;   // FR-TL-06 Ausschalthysterese
constexpr float BRAKE_FULL_MS2  = 5.0f;   // FR-TL-06 Saettigung (100 %)
constexpr float ESS_ON_MS2      = 5.0f;   // FR-TL-07 Notbrems-Blinken ein
constexpr float ESS_OFF_MS2     = 3.0f;   // FR-TL-07 Hysterese aus
constexpr uint32_t BRAKE_MIN_HOLD_MS = 300;  // FR-TL-06 Mindesthaltezeit

// ---- Motion-Filter Stufe 1 — Normbetrags-Gate (Feldtest 06.08.2026) -------
// Physikalischer Diskriminator ueber den Betrag des Beschleunigungsvektors
// (Static/Dynamic/Shock) statt reiner atan2f-Nickschaetzung, s.
// docs/Validierung/stufe1_normgate.md. Ersatz fuer den per r=-0,132 (n=939)
// belegten Fehlbefund (Scheinneigung bei anhaltender Bremsung).
constexpr float MOTION_NORM_STATIC_BAND = 0.12f;  // m/s^2, vorlaeufig, feldzuparametrieren.
// Umrechnung Winkelfehler-Toleranz -> Band ist PYTHAGOREISCH, nicht linear
// mit g skaliert: a = sqrt((g+delta)^2 - g^2). delta=0,12 -> a=1,539 m/s^2
// (g=9,80665) -- Reserve zur 2,0-m/s^2-Ansprechschwelle (BRAKE_ON_MS2).
// Umkehrformel fuer die spaetere Feldparametrierung (Zielwinkel a bekannt):
// delta = sqrt(a^2 + g^2) - g.
constexpr float MOTION_NORM_JERK_DELTA  = 2.0f;   // m/s^2 je 10 ms, dt-normiert; vorlaeufig
constexpr float MOTION_NORM_SHOCK_DELTA = 6.0f;   // m/s^2, reines Betrags-Rueckfallkriterium; vorlaeufig

constexpr uint32_t MOTION_SHOCK_HOLD_MS           = 200;   // ms, Halten je Shock-Episode
constexpr float    MOTION_SHOCK_RESET_S           = 0.5f;  // s, durchgehend shockfrei, bevor die kumulative Shock-Zeit genullt wird
constexpr float    MOTION_SHOCK_MAX_CONTINUOUS_S  = 1.0f;  // s, Zwangsfreigabe -> Regime DYNAMIC (dauerhaft raue Fahrbahn friert sonst das Bremslicht ein)

// TAU_S=0,49s stammte aus dem alten alpha=0,98 @ 10 ms und war nie fuer
// dieses System eigenstaendig begruendet. Seit das explizite Anker-Fenster
// existiert (atan2f-Seed erst bei abgeschlossener Verankerung, s.
// MOTION_ANCHOR_WINDOW_S), muss das laufende STATIC-Filter die
// Startkonvergenz nicht mehr leisten -- es fuehrt nur noch Fahrbahnneigung
// waehrend der Fahrt nach (Zeitkonstante Sekunden bis Minuten realistisch).
// Sicherheitspruefung: ein Steigungssprung von 10% = 5,7 Grad erzeugt
// g*sin(5,7 Grad)=0,98 m/s^2, deutlich unter BRAKE_ON_MS2=2,0 -- ein
// traeges Filter ist hier unkritisch (belegt in T11, s. stufe1_normgate.md
// "Totzone des STATIC-Bands").
constexpr float MOTION_COMPL_TAU_S = 3.0f;  // s, dt-normierte STATIC-Zeitkonstante

// TAU_SLOW=90s ist erst durch die zweistufige Gyro-Bias-Kalibrierung
// zulaessig: stationaerer Fehler eps = b*tau = 0,005 deg/s * 90 s
// = 0,45 deg = 0,077 m/s^2 (b = realistischer Restbias NACH Stufe 1, s.
// MOTION_GYRO_BIAS_*).
constexpr float MOTION_COMPL_TAU_SLOW_S = 90.0f;  // s, DYNAMIC-Zeitkonstante NACH abgeschlossener Bias-Kalibrierung
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

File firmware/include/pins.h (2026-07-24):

// pins.h — GPIO-Belegung (Bible Kap. 4.2, [gesichert])
// Struktureller/sicherheitsrelevanter Wert -> fest im Code (FR-CFG-01).
#pragma once

// I2C-Bus (BMP280 0x76 + MPU6050 0x68)
constexpr int PIN_I2C_SDA   = 21;
constexpr int PIN_I2C_SCL   = 22;

// UART2 -> Quectel L86 GNSS (9600 Bd)
constexpr int PIN_GNSS_RX   = 16;   // <- L86 TXD1
constexpr int PIN_GNSS_TX   = 17;   // -> L86 RXD1

// 433-MHz-Empfaenger SRX882S (kein Strapping-Pin)
constexpr int PIN_RF_DATA   = 4;

// LED-Kanaele ueber IRLZ44N (Gate 100R, Pull-Down 10k). PWM 5 kHz (CON-02).
constexpr int PIN_BLINK_LEFT  = 25;   // gelbe LED links  (Q1)
constexpr int PIN_BRAKE_LIGHT = 26;   // rote LED  Schluss-/Bremslicht (Q2)
constexpr int PIN_BLINK_RIGHT = 27;   // gelbe LED rechts (Q3)

// Hinweis: MPU6050-INT ungenutzt (GPIO4 durch RF belegt) -> Polling.

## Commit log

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2026-07-25 fix(motion): Brems-Richtung MOTION_BRAKE_SIGN am Board kalibriert (+1 statt -1) + Tests angepasst
    [config.h, test_motion_filter.cpp]
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2026-07-26 feat(baro): BMP280-Treiber FORCED-Mode + zentrale I2C-Bus-Init (M5 Teil A)
    Rohdaten-Treiber (Druck/Temperatur, keine Hoehe — FR-SYS-01) im FORCED-Mode
    (Weather-Monitoring-Profil x1/x1, IIR aus), Trigger/Read auf zwei ~1-Hz-Zyklen
    entkoppelt (BARO_FORCED_CYCLE_MS) statt NORMAL-Dauerbetrieb, da Dauerbetrieb
    +2,6 °C Selbsterwaermung zeigte. Wire.begin()/setTimeOut() zentral einmalig in
    main.cpp/setup() statt im IMU-Treiber; imu_driver/bmp280_driver sind reine
    Busnutzer (FR-SNS-03). Am Board geflasht, Druck/Temperatur gegen Referenz
    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
2026-07-26 feat(gnss): L86-Treiber + Fix-Statuslogik (M5 Teil B), UART/Parsing validiert
    gnss_driver (UART2, TinyGPSPlus, nicht-blockierendes gnssPump() jeden
    loop()-Durchlauf) liefert Rohwerte (FR-SYS-01); gnss_fix bewertet den
    Fix-Status (NO_DATA/NO_FIX/FIX_OK, FR-TEL-05) hardwarefrei mit Host-Test.
    Optionaler Sensor (FR-STA-05): kein Fix/keine Daten beeinflussen Licht/
    Blinker nicht. Am Board geflasht — Drinnen-Test zeigt NO_FIX (nicht NO_DATA),
    d. h. NMEA-Datenfluss + Parsing sind bewiesen; ein echter Fix-Vergleich
    braucht freie Himmelssicht.
    [config.h, main.cpp]
2026-07-27 feat(imu): I2C-Recovery + Plausibilitaet + Fail-Safe (FR-SNS-04/05, FR-STA-04), am Fehlerfall verifiziert
    Neues imu_health (Wertebereich, Frozen-, Sprung-Plausibilitaet, gestufte
    Recovery, Eskalations-Vertrauen ueber N konsekutive plausible Zyklen) haelt
    den Bremspfad bei IMU-/I2C-Aussetzern sicher auf Dauer-Schlusslicht statt zu
    haengen oder mit Muelldaten fehlzuloesen. imu_driver: imuRead() prueft den
    Bus per WHO_AM_I statt sich auf getEvent() zu verlassen, FSR auf +-16 g
    (Fahrrad-Stoesse), Recovery-Stufen (Soft-Reinit, SCL-Clock-Release ueber
    rohe gpio_*-Calls statt pinMode(), da PeriMan bei haengendem Bus selbst
    blockiert). motion_filter::reset() verhindert einen dt-Sprung-Artefakt nach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
    [config.h, main.cpp, test_motion_filter.cpp]
2026-07-27 docs: Wissensdatenbank nach Härtung Teil 1 nachgezogen
    roadmap/current_context: Härtung Teil 1 (I2C-Recovery, Plausibilitaet,
    Fail-Safe) abgeschlossen und verifiziert (4096d4d); naechster Schritt
    Haertung Teil 2 (Watchdog FR-SAF-03), danach Telemetrie+BLE. decision_log:
    5 neue Architekturentscheidungen aus der Haertung. lessons_learned: ESP32-
    Core-Wire.end()/PeriMan-Falle bei haengendem I2C-Bus (Root Cause) +
    "Host-Tests allein finden keine Fehlerfall-Bugs am realen Bus". open_issues:
    TODO(offen)-Schwellen der IMU-Plausibilitaet/Recovery, SCL-Timing-
    Verifikation, GNSS-Freilandtest, BMP280-Temperatur-Retest.
2026-07-27 feat(safety): Task-Watchdog + Reset-Reason-Diagnose (FR-SAF-03), am Hang verifiziert
    esp_task_wdt_reconfigure() (mit esp_task_wdt_init()-Fallback) statt init():
    dieser Core initialisiert den TWDT bereits vor setup() (sdkconfig
    CONFIG_ESP_TASK_WDT_INIT=y, Default 5 s), erneutes init() wuerde
    ESP_ERR_INVALID_STATE liefern. enableLoopWDT() registriert den loopTask;
    der Arduino-Core fuettert den TWDT danach automatisch vor jedem loop()-
    Aufruf, kein manueller Reset noetig. esp_reset_reason() setzt beim Boot ein
    Diagnose-Flag (WDT-/Panic-Reset) fuer die spaetere Telemetrie. Temporärer
    'H'-Hang-Hook in taskConfigConsole() (hinter DEBUG_SERIAL) zur Verifikation.
    Am Board verifiziert: 'H' gesendet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
    [main.cpp]
2026-07-27 docs: Härtung Teil 2 (Watchdog) abgeschlossen — nächster Schritt Telemetrie+BLE
    roadmap/current_context: Task-Watchdog + Reset-Reason-Diagnose (FR-SAF-03)
    verifiziert und committet (17d18bc). Naechster Schritt M5-Rest:
    Telemetrie-Frame + BLE.
2026-07-28 feat(telemetry): 80-Byte-Frame + RAM-Ringpuffer (FR-TEL-02/03/04/06), host-getestet
    telemetry_frame: gepacktes 80-Byte-Layout (Version, Timestamp, IMU 6 Achsen
    + Bremsverzoegerung, BMP, GNSS inkl. UTC, Status-Byte-Block), memcpy-basierte
    Serialisierung ohne struct-Cast (keine Alignment-Annahmen). lat/lon als
    double im Struct, Downcast auf float erst beim Serialisieren. telemetry_buffer:
    Ringpuffer auf bereits serialisierten Byte-Slots (RAM-Bedarf exakt
    RINGBUFFER_FRAMES * TELEMETRY_FRAME_SIZE), FIFO-pop(), Ueberlauf
    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
2026-07-28 docs: Bible 0.11 — App-Plattform native iOS (Core Bluetooth) statt PWA
    Kernentscheidung: Web Bluetooth wird von iOS/Safari nicht unterstuetzt,
    zudem Vorgabe des BA-Betreuers -- App wird als native iOS-App (Swift/
    SwiftUI, Core Bluetooth) statt als PWA umgesetzt. Firmware und BLE-
    Interface (GATT-Service, 80-Byte-Frame, FR-SYS-04) bleiben unveraendert
    und client-agnostisch, M5 Teil C2 vollstaendig wiederverwendbar.
    Kap. 7 komplett auf "App (iOS)" umgeschrieben (Technik, Entwicklung in
    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
2026-07-30 docs: BLE-Brownout-Fallstudie + Datenstruktur (Board-Tausch DevKitC-32E, Root Cause Hardware)
    Neue docs/ble_brownout_fallstudie.md: ausformulierte, zitierfaehige
    Fallstudie zum Brownout-Bootloop bei NimBLEDevice::init() (M5 Teil C2).
    Zehn systematische Tests (Bracket-Logging, Isolationstest, Nur-USB,
    TX-Leistung, CPU-Takt, Kondensatoren an 3V3+Vin, MT3608-Spannung,
    Multimeter-Verifikation, BOD-Abschaltung) grenzen Firmware, Lastverteilung,
    Zwei-Quellen-Konflikt, Software-Gegenmassnahmen und Verdrahtung als
    Ursache aus. Root Cause: Spannungsregler (AMS1117) des Altboards liefert
    die BLE-RF-Kalibrierungs-Transiente nicht. Entscheidung: Board-Tausch auf
    Espressif ESP32-DevKitC-32E (WROOM-32E, p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
2026-08-01 feat(telemetry): M5 Teil C2 — BLE-Transport (NimBLE, FR-TEL-01, FR-SYS-04)
    BLE-Notify-Server (ble_telemetry) an Frame+Ringpuffer aus Teil C1
    angeschlossen: taskTelemetry() sendet live bei bestehender Verbindung,
    puffert sonst in den RAM-Ringpuffer (FR-TEL-04) und liefert nach
    Reconnect bis zu BLE_BACKFILL_FRAMES_PER_TICK=5 alte Frames pro Tick
    nach. advertiseOnDisconnect(true) haelt das Geraet nach Trennung
    wiederverbindbar. TX-Power reduziert (BLE_TX_POWER_DBM=-12, TODO(offen)
    Feldverifikation) fuer die Energiebilanz.
    Zwei Bugs beim Hardware-Test auf dem Ersatzboard (Espressif
    ESP32-DevKitC-32E, s. docs/ble_brownout_fallstudie.md) gefunden und
    behoben:
    - Advertising ohne Namen: NimBLEDev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
    [config.h, main.cpp]
2026-08-01 feat(ble): C2 BLE-Telemetrie am realen System validiert (Board-Tausch DevKitC-32E)
    Isolations-Scaffold aus M5 Teil C2 entfernt: BLE_ISOLATION_TEST-Zweig
    (setup()/loop()) komplett raus, BLE_ENABLED-Feature-Flag aufgeloest --
    drivers::bleBegin() laeuft jetzt unbedingt in setup(), BLE ist fester
    Bestandteil des Normalbetriebs. Kein Register-BOD-Disable im Code (BOD
    regulaer aktiv), keine Debug-/Testreste ausser dem 'H'-Watchdog-Hang-Hook
    hinter DEBUG_SERIAL. Veralteten config.h-Kommentar zu BLE_TX_POWER_DBM
    korrigiert (TX-Power war nie die Brownout-Ursache, s. u.).
    Nach Einloeten des Ersatzboards (Espressif ESP32-DevKitC-32E, WROOM-32E)
    stufenweise am realen System verifiziert: Pin-/Logiktest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
    [config.h, main.cpp]
2026-08-05 feat(telemetry): brake_light_pct ins Frame (Schema v2, Eingang+Ausgang für Bremslicht-Validierung)
    Telemetrie-Frame um brake_light_pct (uint8, Offset 80, 0..100) erweitert:
    die tatsaechlich von tail_light_fsm kommandierte Ruecklicht-Duty, derselbe
    Wert wie an drivers::setDutyPercent() uebergeben. Ergaenzt brake_decel_ms2
    (roher motion_filter-Eingang, unveraendert bei Offset 30) um den
    zugehoerigen Ausgang -- erlaubt App/Auswertung den Vergleich Eingang vs.
    Ausgang der Bremskennlinie (FR-TL-06-Validierung, inkl. Fail-Safe-Gating,
    Hysterese, Mindesthaltezeit).
    Frame 80->81 Byte, TELEMETRY_SCHEMA_VERSION 1->2 (FR-TEL-06). Zwei neue
    Host-Tests (Feld-Roundtrip bei Offset 80, Randwerte 0/100). N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
    [config.h, main.cpp]
2026-08-06 Aktueller Stand: IOS-App + Firmware (brake_light_pct/Schema v2) + Doku
    [bench_A_kennlinie_rampe.csv, bench_B_zeitverhalten_sprung.csv, bench_C_failsafe.csv]
2026-08-07 AP1: TelemetryFrame um 13 v3-Felder als Optionals erweitern
    v2-Felder bleiben nicht-optional; v3-Felder (Offsets 81-112) optional (nil =
    im Frame nicht vorhanden, AR-CONN-04). Reiner Werttyp, keine Verhaltensaenderung
    (Decoder/Versionsregel folgen in AP2). SmartBikeCore bleibt UI-frei.
    Tests: SmartBikeCore 47 gruen, App 13 gruen (60 gesamt).
2026-08-07 feat(telemetry): Schema v3 (113 Byte) + Normbetrags-Gate-Reparaturrunde
    Firmware (Claude Code):
    - Telemetrie-Frame v3 (81->113 Byte, Schema-Version 2->3): GNSS-Referenz-
    beschleunigung (gnss_speed_ref, rein beobachtend, E1/E5), Filter-Innen-
    sicht (pitch_rad/gyro_bias_rads/bias_calibrated), 100-Hz-Fenster-
    aggregate (telemetry_window_agg: norm_delta_min/max, jerk_max, Regime-
    Zaehler, dt_max_ms, loop_max_us fuer NFR-RT-04). Offsets 0-80 byte-
    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
2026-08-07 feat(persistence): AP5 — TrackSample um 13 v3-Felder additiv erweitert
    TrackPoint (Core) und TrackSampleEntity (@Model) um die 13 v3-Analyse-/
    Aggregatfelder als optionale Properties ergaenzt (nil = Alt-/v2-Daten).
    Mapping Core-Werttyp <-> @Model in beiden Richtungen (SwiftDataStore),
    RideManager.ingest schreibt die Felder + frame_version je Sample.
    temperature_c wird jetzt persistiert (fehlte bisher im @Model); bleibt im
    Modell, faellt erst im CSV-Export (AP7). Additive Optionals => automatische
    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
2026-08-07 feat(recording): AP6 — umschaltbarer Aufzeichnungsmodus 1 Hz / 10 Hz
    RecordingMode (Core, UI-frei): 1 Hz (Standard) / 10 Hz (Validierung) mit
    float-robuster Bucket-Verdichtung (Nudge +1e-9 gegen Uhr-Akkumulation, E-4).
    RideManager: setMode mit Umschaltsperre (nur außerhalb der Aufzeichnung),
    mode-abhängige Decimation, gepufferte Batch-Persistenz (~1 Save/s statt
    1 Save/Sample, AR-NFR-PERF-01) — Live-Kennzahlen entkoppelt, Main-Thread frei.
    RideRepository.appendBatch (ein save() im Hintergrund-ModelActor); Settings-UI
    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
2026-08-10 Einbaulage-Transformation (IMU_MOUNT_SIGN_*) + Messfahrt-/Schaltplan-Doku
    Rueckabbildung der 180-Grad-Platinendrehung an der Treibergrenze
    (imu_driver.cpp), hardwarefrei testbar ueber die neue
    lib/logic/imu_mount_orientation.h. decision_log.md und open_issues.md
    um die getroffene Entscheidung bzw. das Pruefkriterium ergaenzt.
    Dazu die seit Commit 1178017 parallel entstandene Dokumentation:
    Messfahrt-Auswertung vom 08.08.2026, KiCad-Schaltplan samt PDF/Doku,
    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
    [schaltplan_fahrrad_ruecklichtsystem.kicad_sch]
2026-08-10 Firmware-Abschluss: FR-TL-06-Defekt B5, Debug-Aufraeumen, Umfangsschnitt
    Ein Durchlauf vor dem Einfrieren der Firmware:
    - Fix Defekt B5 (Feldtest 08.08.2026): tail_light_fsm haelt den
    Bremslicht-Wert waehrend der 300-ms-Mindesthaltezeit jetzt korrekt --
    der else-Zweig ueberschrieb held_brake_duty_pct_ bisher auch unterhalb
    on_ms2 mit dem Schlusslichtwert, wodurch die Haltezeit optisch
    wirkungslos war. Regressionstest deckt einen Bremsvorgang ab, der
    monoton durch das Hystereseband faellt.
    - Alle "TODO(temp debug)"-Serial-Ausgaben entfernt ([R1/R2], [Baro],
    [GNSS]); DEBUG_SERIAL auf Auslieferungsstand (false).
    - FR-CFG-02/FR-CFG-03 (serielles Kalibrier-Interface, NVS-Konfiguratio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
    [config.h, main.cpp]
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2026-08-13 13.08.2026 Changes
    [schaltplan_fahrrad_ruecklichtsystem.kicad_sch]
2026-08-17 Upload CSV: 170826
    [SmartBikeRearLight-Fahrt-2026-08-06-2220.csv, SmartBikeRearLight-Fahrt-2026-08-06-2226.csv, SmartBikeRearLight-Fahrt-2026-08-06-2229.csv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]
